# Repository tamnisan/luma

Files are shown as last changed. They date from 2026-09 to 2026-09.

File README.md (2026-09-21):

<div align="center">

# Luma Retrofit: Open-Source Urine Test Strip Reader

**Open-source CAD for a removable urine test strip reader (a urinalysis device) that retrofits into existing public toilets. It needs no drilling, new wiring or plumbing.**

**[Website and live 3D model](https://tamnisan.github.io/luma/)** · **[Build guide](https://tamnisan.github.io/luma/build-guide.html)** · **[Download ZIP](https://github.com/tamnisan/luma/archive/refs/heads/main.zip)**







[Quick start](#quick-start) •
[Open the model](#open-the-model) •
[Design](#design-overview) •
[Build from source](#building-from-source) •
[Status](#project-status) •
[Contributing](#contributing)

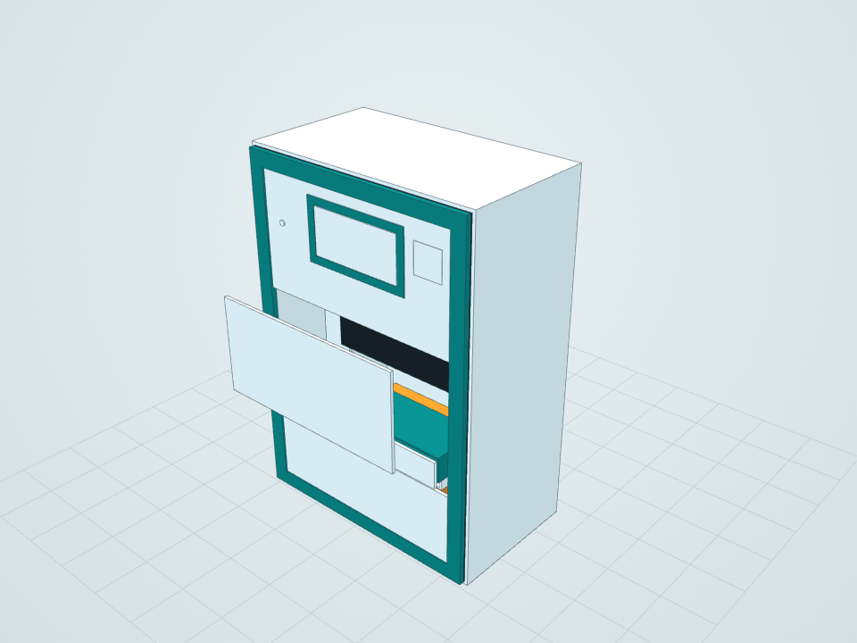
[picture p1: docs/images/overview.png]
Luma reader enclosure, isometric view


</div>

> [!WARNING]
> **This is an engineering prototype (Rev A), not a medical device.** It is not a fabrication release and has not been clinically validated. The sample transport, clamp mechanisms, mount load capacity, sealing and measurement accuracy have not been tested. If you build or deploy anything based on this design, you are responsible for safety, structural and regulatory approval. Read [ENGINEERING.md](ENGINEERING.md) first.

## About

Luma is a compact reflectance reader for urine test strips, designed to be added to public toilets that already exist. One common enclosure takes interchangeable, reversible mounts, so an installer can choose whichever fits the site: a partition edge, a grab-rail post, the top of a cubicle wall, a free-standing pedestal, a smooth tiled surface or structural steel. It runs from a DC supply or a removable battery.

The intended workflow keeps clean and used material apart:

1. The user places a wetted strip in a keyed disposable carrier.
2. The reader checks that the cover is closed and a strip is present.
3. An RGB sensor with two white LEDs scans the pads.
4. The result is shown privately on the display.
5. The used strip goes into a closed waste cartridge.

Unused strips stay in a separate sealed cassette, away from the measurement path.

It is an open-hardware starting point for anyone working on **point-of-care diagnostics**, **smart toilets** or **public health kiosks**. The design reserves space for an **Arduino Uno** controller and a **TCS34725 RGB colour sensor**, and the enclosure is designed for **3D printing** in PC-ABS.

The whole model is **generated by code**: a C# program drives the SolidWorks API, builds every part and assembly from a single dimension table, then checks the result. It is also exported to open formats, so anyone can view, modify, 3D-print or re-use the design **without owning SolidWorks**.

## Highlights

- **109 native SolidWorks parts**, one assembly and a general-arrangement drawing
- **6 reversible mounts × 2 power options = 12 configurations**, plus installed, service and exploded views
- **Works without CAD software:** an offline 3D viewer (double-click `START.html`), STEP files for any CAD program and STL files for 3D printing
- **Parametric and reproducible:** the layout comes from one table in [`src/LumaBuilder.cs`](src/LumaBuilder.cs), and each rebuild is written to a new timestamped folder
- **Checked on every build:** no static interferences in any of the 12 mount/power configurations, all 125 sketches fully constrained, and every part within 0.15 mm of its BOM envelope
- **Documented:** load and stability assumptions, installation site survey, service sequence, mounting-compatibility matrix and cost allowances in [ENGINEERING.md](ENGINEERING.md)

## Gallery

<table>
  <tr>
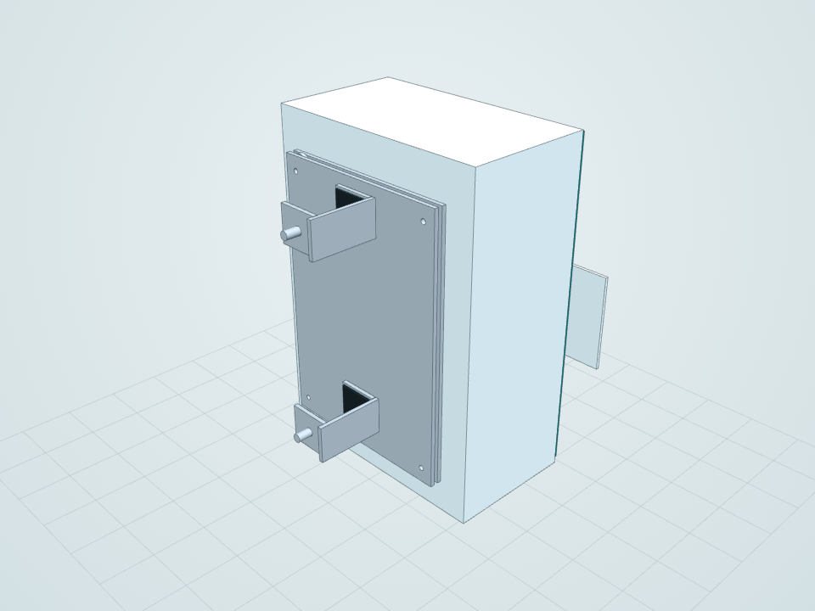
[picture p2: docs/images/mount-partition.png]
Partition clamp mount
    <td align="center"><br><b>Partition clamp</b><br><sub>Padded jaws for 12–50 mm panels</sub></td>
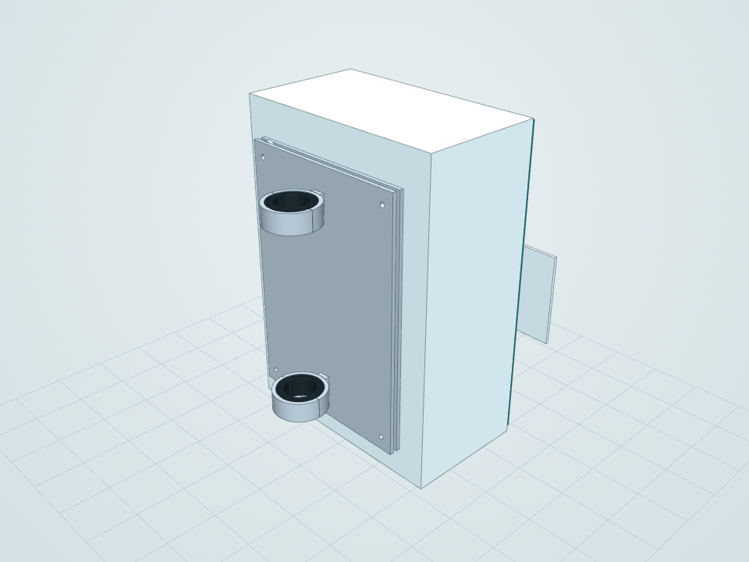
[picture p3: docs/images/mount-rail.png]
Rail clamp mount
    <td align="center"><br><b>Rail clamp</b><br><sub>Split clamp on a 32 mm post</sub></td>
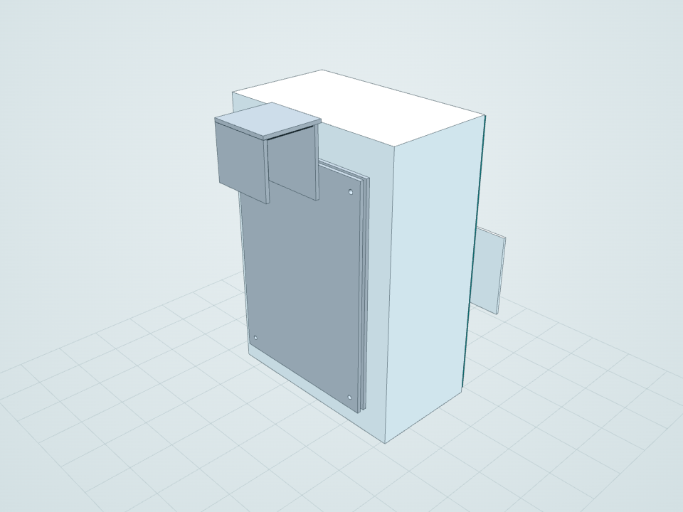
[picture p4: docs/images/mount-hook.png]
Over-partition hook mount
    <td align="center"><br><b>Over-partition hook</b><br><sub>55 mm padded gap</sub></td>
  </tr>
  <tr>
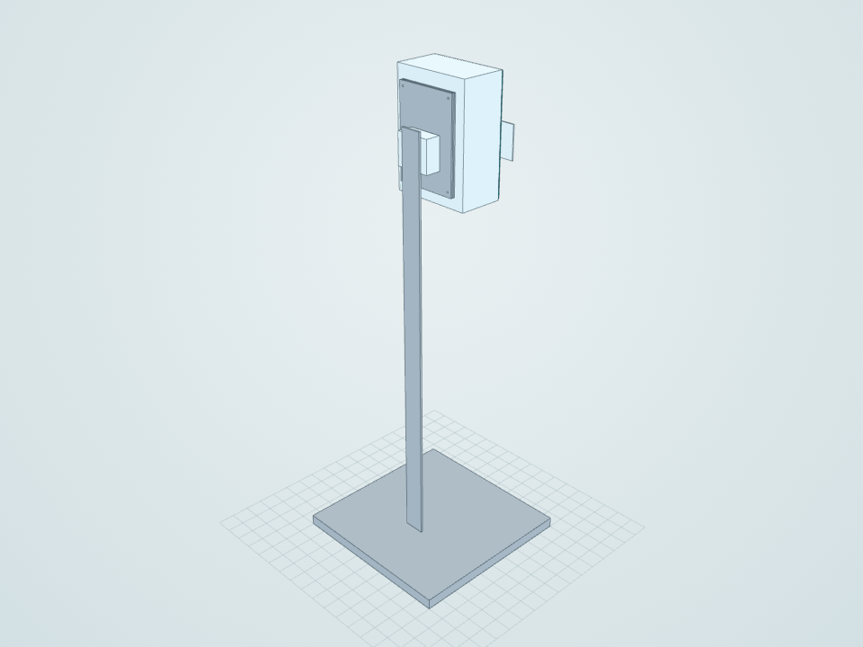
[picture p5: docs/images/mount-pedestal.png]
Floor pedestal mount
    <td align="center"><br><b>Floor pedestal</b><br><sub>Ballasted base, no anchors</sub></td>
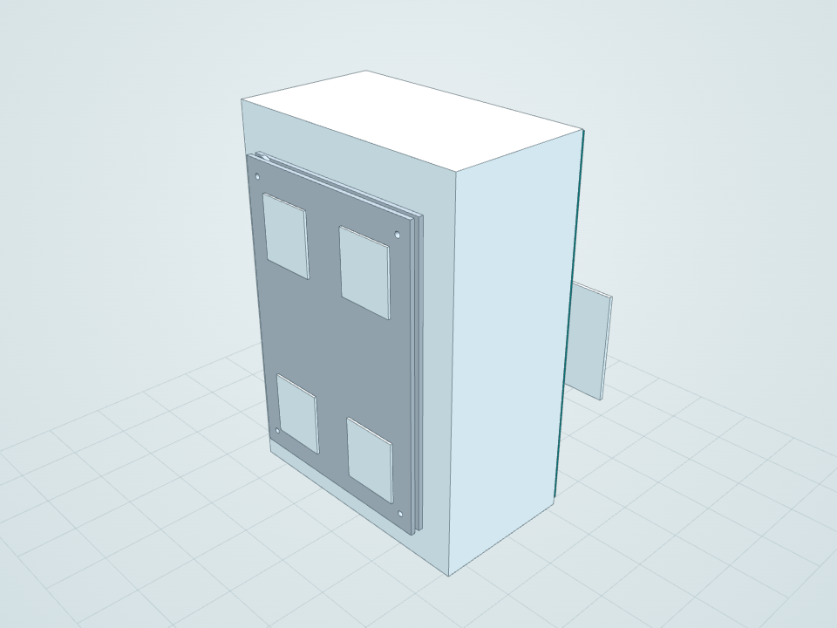
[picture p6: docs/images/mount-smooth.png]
Smooth-surface pad mount
    <td align="center"><br><b>Smooth-surface pads</b><br><sub>Removable pads + tether (reserved)</sub></td>
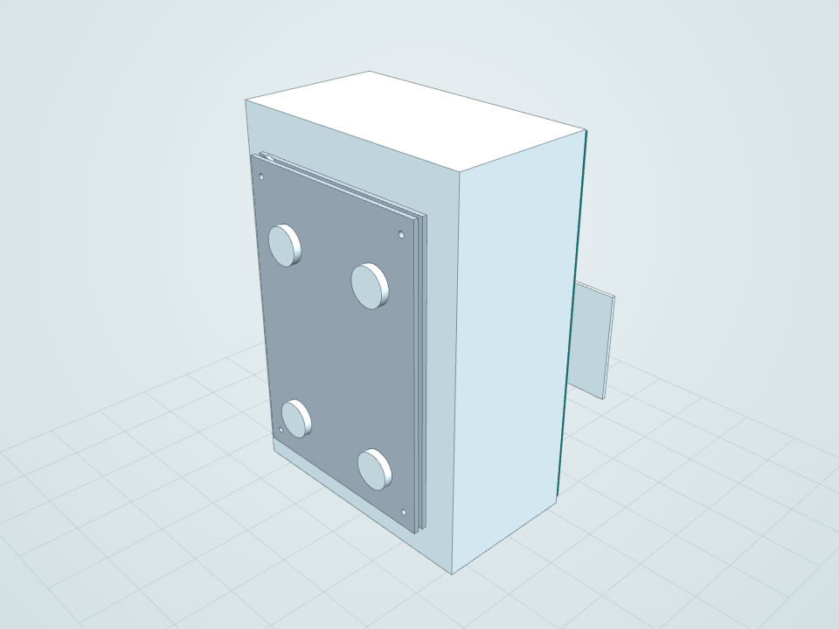
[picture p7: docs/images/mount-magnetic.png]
Magnetic mount
    <td align="center"><br><b>Magnetic mount</b><br><sub>Magnet pots + tether (reserved)</sub></td>
  </tr>
  <tr>
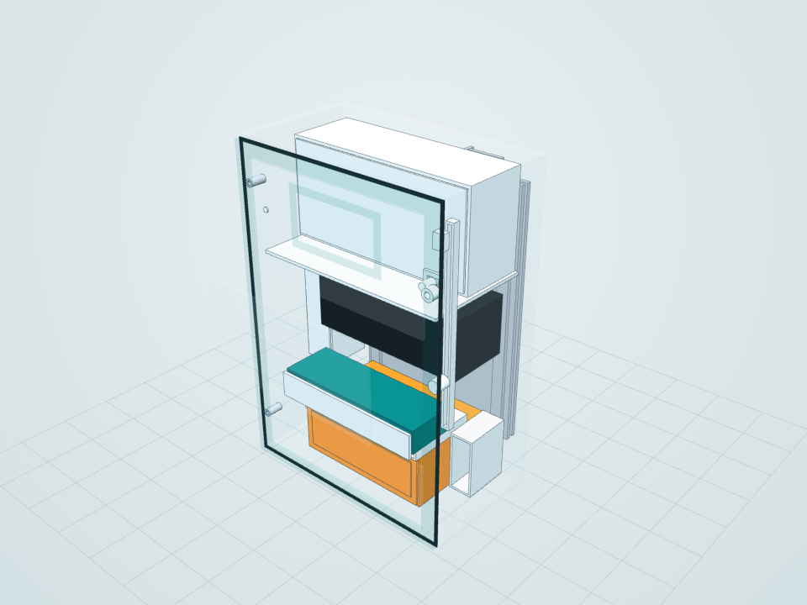
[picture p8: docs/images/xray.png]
X-ray view of the internal layout
    <td align="center"><br><b>Internal layout</b><br><sub>X-ray through the housing</sub></td>
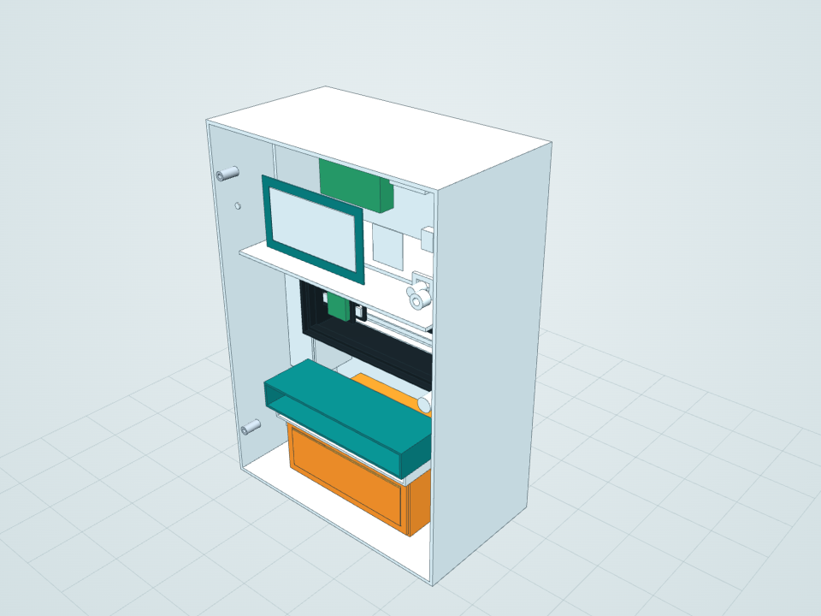
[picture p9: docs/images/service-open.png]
Service view with covers removed
    <td align="center"><br><b>Service access</b><br><sub>Front covers removed</sub></td>
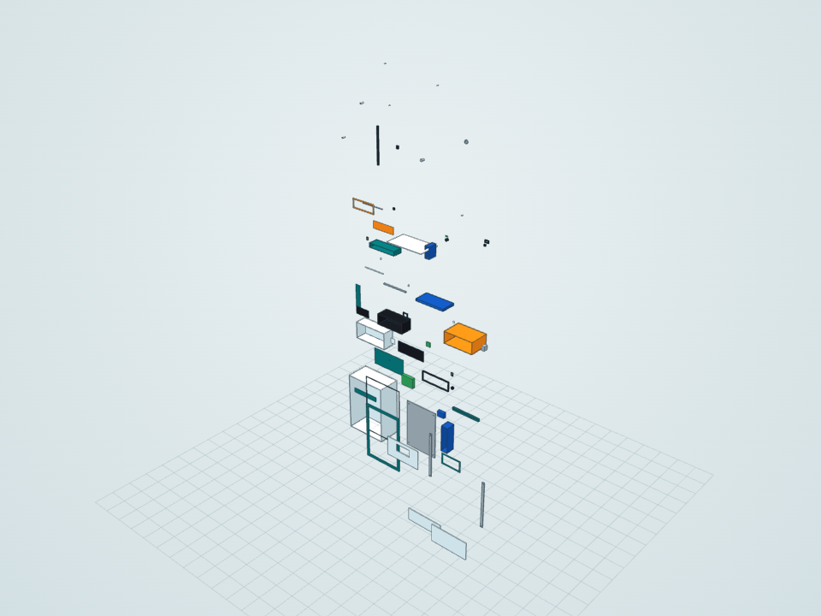
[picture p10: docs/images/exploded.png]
Exploded parts layout
    <td align="center"><br><b>Exploded layout</b><br><sub>Separated-parts review</sub></td>
  </tr>
</table>

<details>
<summary><b>Installed on host infrastructure (illustrative)</b></summary>
<br>
<table>
  <tr>
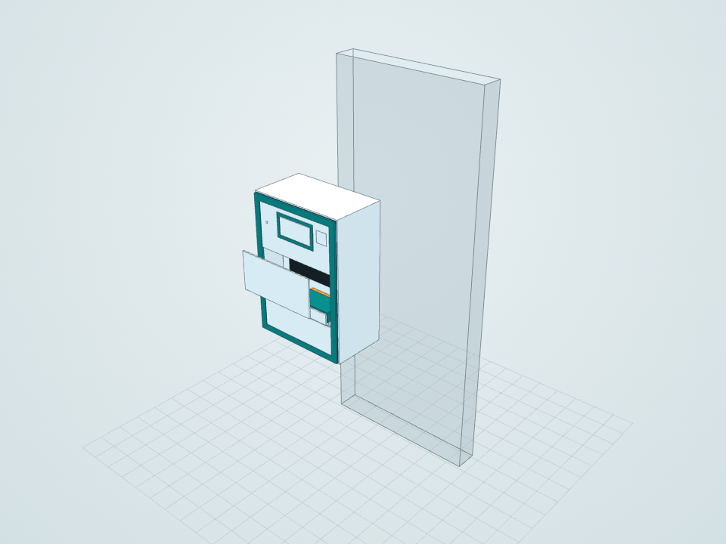
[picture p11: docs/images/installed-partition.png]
Installed on a partition
    <td align="center"><br><sub>Partition</sub></td>
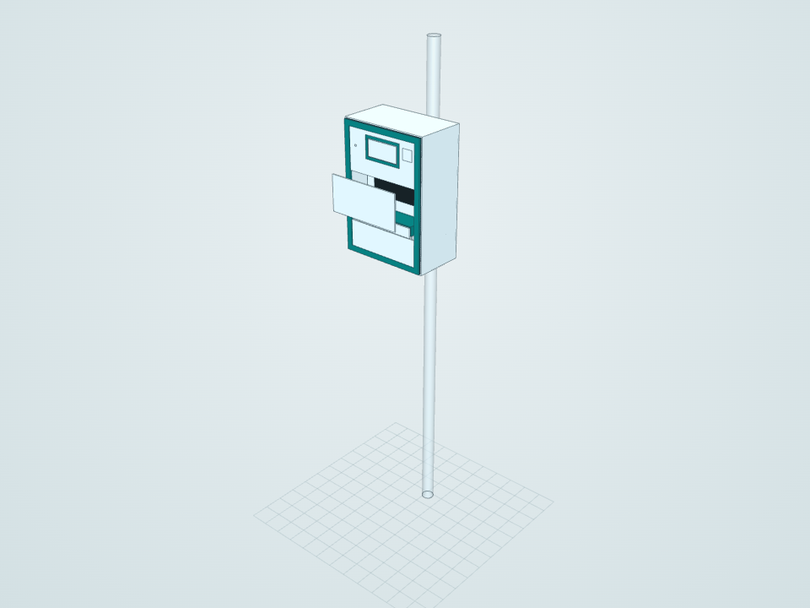
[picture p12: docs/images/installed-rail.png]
Installed on a rail
    <td align="center"><br><sub>Rail / post</sub></td>
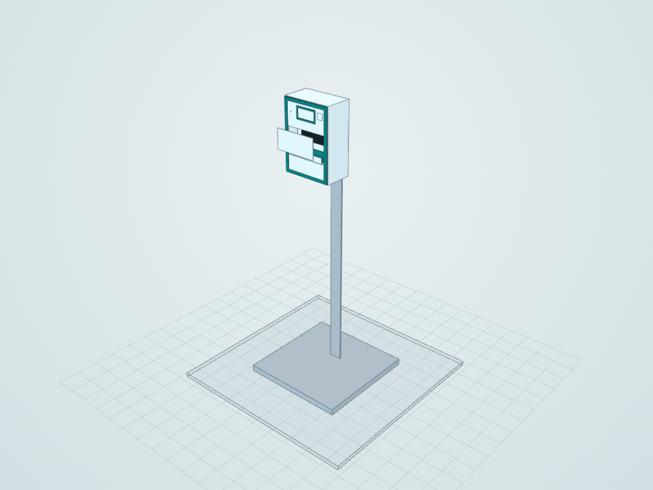
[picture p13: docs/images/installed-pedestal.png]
Installed on a floor pedestal
    <td align="center"><br><sub>Floor pedestal</sub></td>
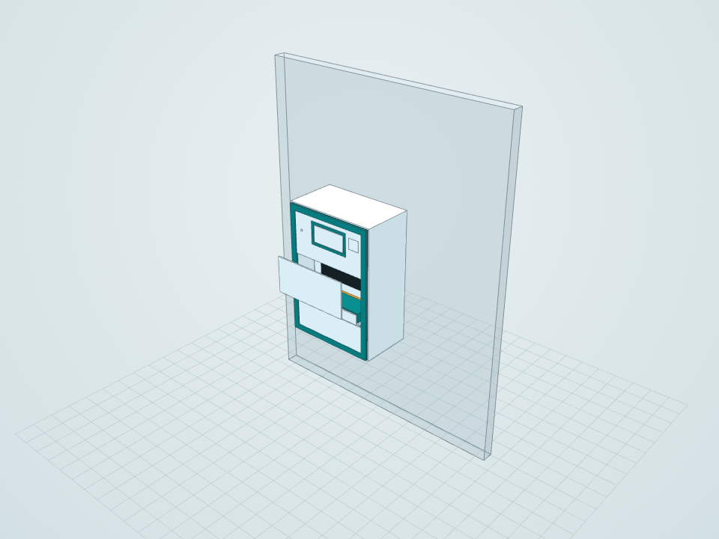
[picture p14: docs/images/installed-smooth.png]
Installed on a smooth wall
    <td align="center"><br><sub>Smooth wall</sub></td>
  </tr>
</table>
The host geometry (panel, post, floor, wall) is reference only and is not part of the product.
</details>

## Quick start

1. **[Download the ZIP](https://github.com/tamnisan/luma/archive/refs/heads/main.zip)** (or **Code → Download ZIP** on GitHub), or clone it:
   ```bash
   git clone https://github.com/tamnisan/luma.git
   ```
2. **Extract** the zip (right-click → *Extract All*). Don't open files from inside the zip, because the viewer and the SolidWorks assembly need their neighbouring files.
3. **Double-click `START.html`.** The interactive 3D model opens in your browser, offline, with nothing to install.

## Open the model

| What you have | What to open |
|---|---|
| **Just a web browser** | `START.html` → [browser 3D viewer](#1-browser-3d-viewer-no-install) |
| **FreeCAD, Fusion 360, Onshape, Inventor, Solid Edge, CATIA, …** | [`exports/step/`](builds/20260913-163314/exports/step/): one STEP assembly per configuration |
| **SolidWorks 2026 or newer** | [`Luma_Retrofit.SLDASM`](builds/20260913-163314/): native parametric model |
| **A slicer / 3D printer** | [`exports/stl/`](builds/20260913-163314/exports/stl/): one STL per part |
| **Nothing downloaded** | Open any `.stl` in [`exports/stl/`](builds/20260913-163314/exports/stl/) on GitHub; it renders a rotatable 3D preview |

### 1. Browser 3D viewer (no install)

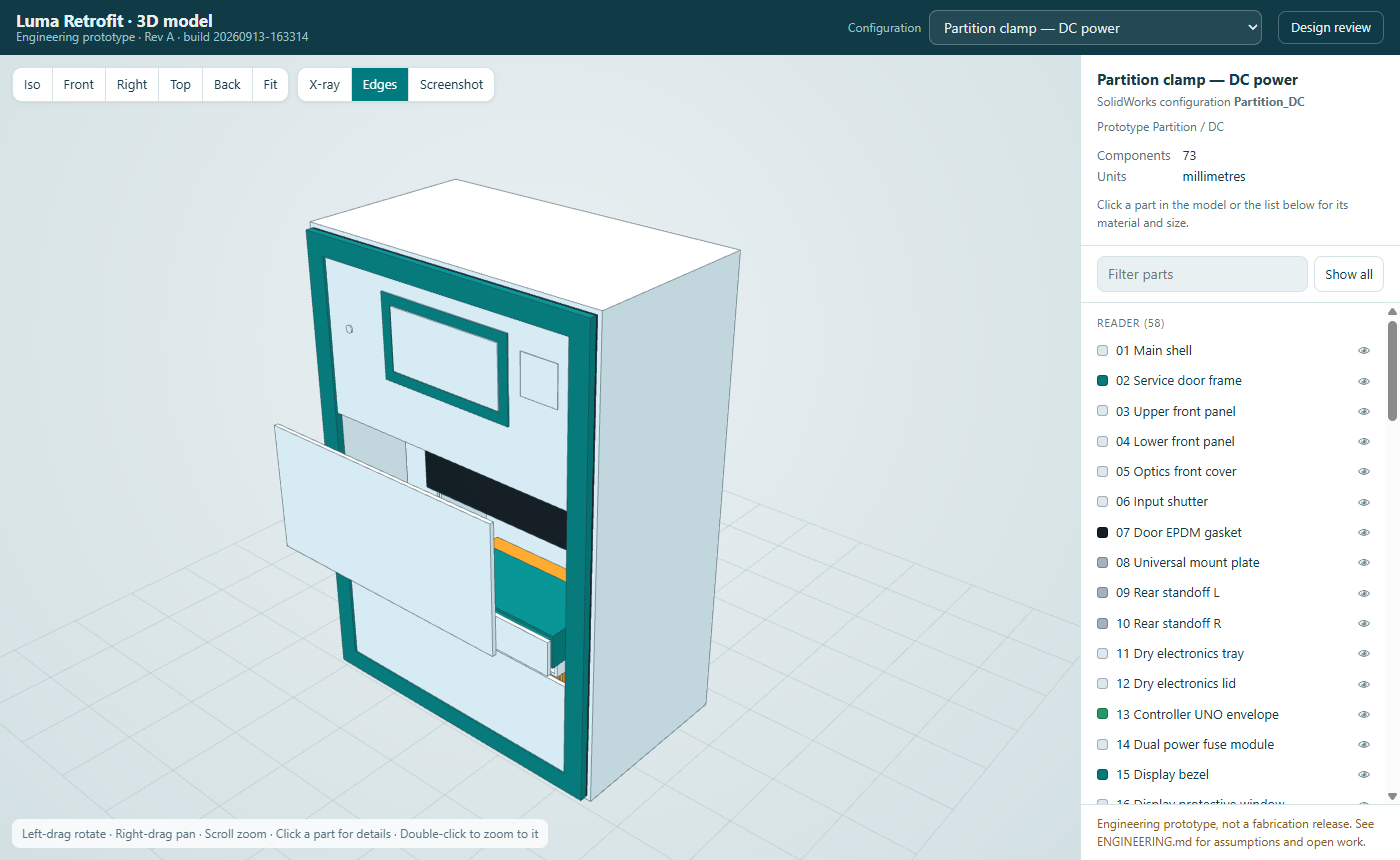
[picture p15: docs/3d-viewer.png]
Luma 3D viewer in the browser


`START.html` opens `builds/20260913-163314/Viewer.html`. It runs offline in current Chrome, Edge, Firefox and Safari.

| Action | How |
|---|---|
| Rotate / pan / zoom | Left-drag / right-drag / scroll |
| Part details (material, process, size, file) | Click a part in the model or in the parts list |
| Zoom to a part | Double-click it |
| See inside the housing | **X-ray** button or `X` |
| Standard views | **Iso / Front / Right / Top / Back** or keys `1`–`5`; `F` to fit |
| Hide or isolate parts | Eye icon in the list, **Isolate** / **Hide** buttons, `H`; `Esc` clears |
| Save an image | **Screenshot** |
| Link to a configuration | Append it after `#`, e.g. `Viewer.html#Rail_Battery` |

A **Design review** link opens [`Review.html`](builds/20260913-163314/Review.html). It holds the dimensioned drawings, native SolidWorks renders, a filterable bill of materials, mass estimates and the engineering record.

> [!TIP]
> **Host the viewer online for free:** in your fork go to **Settings → Pages**, set *Source* to **Deploy from a branch**, choose `main` and `/ (root)`, then save. The model will be viewable at `https://<user>.github.io/<repo>/START.html`.

### 2. STEP (any CAD program)

Each file is a STEP AP214 assembly in millimetres, with colours. Import it with **File → Open / Import**: in FreeCAD use *File → Open*, in Fusion 360 use *Upload*, in Onshape use *Import*.

STEP carries the solid geometry but not SolidWorks' feature history or equations. To change dimensions parametrically, use the generator ([Building from source](#building-from-source)).

### 3. SolidWorks (native, parametric)

Open `builds/20260913-163314/Luma_Retrofit.SLDASM` and keep its `parts/` folder beside it. Choose a configuration in the **ConfigurationManager**. Also included are `Luma_Exploded.SLDASM` (separated-parts assembly) and `Luma_GA.SLDDRW` (general-arrangement drawing).

> [!NOTE]
> SolidWorks files open only in the version that saved them or newer, so these need **SolidWorks 2026+**. The free [eDrawings Viewer](https://www.edrawingsviewer.com/) has the same version requirement. On older versions, use the STEP files.

### 4. STL (3D printing)

These are binary STL files in millimetres, one per part, each in its own coordinate system. Check the `Process` column in [`BOM.csv`](builds/20260913-163314/BOM.csv) first. Parts named `*_envelope` only reserve space for purchased components (Arduino, sensor, battery, motor, …), and items marked COTS should be bought, not printed.

## Build it yourself

The **[build guide](build-guide.html)** ([online](https://tamnisan.github.io/luma/build-guide.html)) covers building a prototype:

- the full parts list with specifications, each checked against the space the CAD reserves: Arduino Uno, TCS34725 colour sensor, white LEDs, micro stepper, 2S battery, switches, and the printed, stainless-steel and EPDM parts
- labelled layout diagrams showing where every component goes (the Arduino sits upright in the upper-left corner of the dry electronics compartment)
- eight assembly steps, each with a picture and a link that highlights those parts in the 3D viewer
- a suggested Arduino wiring table, power path, first power-up tests and the service routine

## Configurations

| Mount | DC power | Battery power | Installed on host (illustrative) |
|---|---|---|---|
| Partition clamp | `Partition_DC` | `Partition_Battery` | `Installed_Partition` |
| Rail clamp | `Rail_DC` | `Rail_Battery` | `Installed_Rail` |
| Over-partition hook | `Hook_DC` | `Hook_Battery` | none |
| Floor pedestal | `Pedestal_DC` | `Pedestal_Battery` | `Installed_Pedestal` |
| Smooth-surface pads | `Smooth_DC` | `Smooth_Battery` | `Installed_Smooth` |
| Magnetic mount | `Magnetic_DC` | `Magnetic_Battery` | none |

There is also `Service_Open` (front covers removed) and the separate exploded assembly. The STEP file for each configuration is `exports/step/Luma_<Configuration>.step`.

## Design overview

| | |
|---|---|
| **Enclosure envelope** | 230 W × 330 H × 134 D mm; 150 mm projection including the rear adapter |
| **Estimated dry mass** | ≈ 5.4 kg (partition / DC). This is an analytic estimate from geometry and assumed densities, not a weighed or certified value |
| **Electronics allowance** | Arduino Uno, TCS34725 RGB sensor, two white LEDs, display, status LED, buzzer, dual power fuse module |
| **Optics** | Enclosed black optical chamber, moving sensor/LED scan carriage on a rail with lead screw and motor, calibration tile |
| **Consumables** | Sealed clean-strip cassette, sample drawer, used-strip waste cartridge with closure slide, drip tray, cleaning-fluid cartridge |
| **Power** | DC connector with cable gland and strain relief, **or** a removable battery tray (75 × 23 × 39 mm protected-pack allowance) |
| **Safety interlocks (reserved space)** | Door interlock, cartridge-present switch, drip-overflow sensor, strip-jam/home sensor, service lock, tether eye |
| **Common mount interface** | 180 × 260 × 4 mm stainless adapter plate, 4 × Ø5 mm holes; no new holes in the building |
| **Materials** | PC-ABS (printed enclosure), black PC-ABS (optics), polypropylene (wetted trays and cartridges), 304 stainless steel (mounts, hinges, fasteners), EPDM (gaskets and pads), polycarbonate (display window) |
| **Prototype cost allowance** | INR 8,867–18,667 before stand, connectivity, labour and validation (planning figures, not quotes) |

| Zone | Layout |
|---|---|
| Dry electronics | Upper tray with sealed lid, full wet/dry barrier below |
| Unused strips | Separate left cassette with removable lid |
| Optics | Right central chamber, black insert, moving RGB/LED carriage, fixed strip datum |
| Sample input | Removable front tray behind a shutter |
| Waste | Lower removable cartridge with closure slide |
| Cleaning | Small fluid-cartridge allowance plus removable wetted inserts |

The full site-suitability rules for each mount, load cases, stability checks, assembly and service sequence, and installer survey are in [ENGINEERING.md](ENGINEERING.md).

## Repository structure

```
luma/
├── START.html                    Opens the 3D viewer
├── index.html                    Project website (GitHub Pages homepage)
├── build-guide.html              Parts list, layout diagrams, assembly steps and wiring (generated by src/Guide.js)
├── assets/site.css               Shared website styles
├── README.md                     This file
├── ENGINEERING.md                Design intent, assumptions, mounting matrix, loads, service, costs, open work
├── LICENSE                       MIT
├── CITATION.cff                  Citation metadata ("Cite this repository")
├── sitemap.xml                   Sitemap for search engines
├── LATEST.txt                    Name of the current build folder
├── docs/                         README and build-guide images, social preview card
├── builds/
│   └── 20260913-163314/          Current build
│       ├── Viewer.html, viewer/  Offline 3D viewer and its model data
│       ├── Review.html           Design review (drawings, renders, BOM, engineering record)
│       ├── Luma_Retrofit.SLDASM  Main assembly (+ Luma_Exploded.SLDASM, Luma_GA.SLDDRW)
│       ├── parts/                109 native SolidWorks parts
│       ├── exports/step/         STEP assembly per configuration
│       ├── exports/stl/          STL mesh per part
│       ├── exports/scene.json    Component placement per configuration
│       ├── BOM.csv               Part envelopes, positions, materials, processes
│       ├── views/                Native SolidWorks renders
│       └── VALIDATION.md, *.txt  Rebuild, sketch, geometry and interference check records
└── src/                          Generator, checks, exporter, viewer and report source
```

## Building from source

The CAD is produced by a pipeline you can re-run, change and extend.

```mermaid
flowchart LR
    A["LumaBuilder.cs<br/>dimension table"] --> B["Parts, assembly,<br/>12 configurations"]
    B --> C["Verify, repair, detail<br/>and interference checks"]
    C --> D["Export.cs"]
    D --> E["STEP per configuration"]
    D --> F["STL per part"]
    D --> G["scene.json"] --> H["Viewer.js: 3D viewer"]
    C --> I["Audit.js + Report.js:<br/>VALIDATION.md, Review.html"]
```

### Requirements

- Windows with **SolidWorks 2026 or newer** and a licence
- .NET Framework 4.x (included with Windows)
- [Node.js](https://nodejs.org) 18+ for the viewer and reports
- Default templates set in SolidWorks (**Tools → Options → Default Templates**)

The SolidWorks install is found through the registry. Set `SOLIDWORKS_DIR` to use a different one.

### Commands

```powershell
# Full rebuild into a new builds\<timestamp> folder (updates LATEST.txt)
powershell -ExecutionPolicy Bypass -File src\Build.ps1

# After editing the current model in SolidWorks: refresh STEP, STL, the 3D viewer and the review
powershell -ExecutionPolicy Bypass -File src\Build.ps1 -ExportOnly

# Zip the current build (e.g. to attach to a GitHub Release)
powershell -ExecutionPolicy Bypass -File src\Package.ps1
```

Run only one builder at a time against a SolidWorks instance. The exporter opens the model read-only and restores your export settings afterwards.

### Changing the design

Every part's size and position is in `Layout()` in [`src/LumaBuilder.cs`](src/LumaBuilder.cs), in millimetres. Edit it and run a full rebuild. Parts are built from sketches and extrusions whose dimensions are linked to global variables. There is no master skeleton or mechanical mates yet, so a change to one part does not resize its neighbours automatically.

| Source | Purpose |
|---|---|
| `src/LumaBuilder.cs` | Generates every part, the assembly and its configurations |
| `src/Verify.cs` | Reopens and rebuilds parts, constrains sketches, measures bodies, checks interference |
| `src/RepairConfigurations.cs`, `Scenes.cs`, `Finalize.cs`, `FinalAudit.cs` | Configuration checks, host reference scenes, exploded assembly, final views |
| `src/HardwareDetails.cs` | Screw clearances, rail-saddle relief, hook-plate separation |
| `src/Export.cs` | STEP per configuration, STL per part, placement data for the viewer |
| `src/Viewer.js`, `src/Viewer.html` | Builds the offline viewer and checks each placement against SolidWorks' own component boxes |
| `src/Audit.js`, `src/Report.js` | Validation record, design review and dimensioned SVG drawings |
| `src/Guide.js` | Website build guide: parts tables, layout diagrams and assembly steps from `BOM.csv` |

## Project status

**Rev A: packaging and layout prototype.** What exists and what still has to be done:

- [x] Native, reproducible CAD for the enclosure, internals and six mounts
- [x] All sketches fully constrained; zero static interferences in all 12 mount/power configurations
- [x] Open-format exports and a browser viewer
- [x] Engineering record: assumptions, load cases, site survey, service sequence, cost allowances
- [ ] Mechanical mates, bearings, travel stops and a motion study for the scan mechanism
- [ ] Detailed strip feed/eject kinematics and jam/carry-over testing
- [ ] Optical bench study: sensor distance, LED angle, pad-specific calibration
- [ ] Seals, drainage and an IP54/IP55 enclosure test
- [ ] Mount load, creep and surface-damage tests; clamp hardware detailing
- [ ] Manufacturing detail: fillets, draft, ribs, bosses, threaded inserts, tolerances
- [ ] Electrical interlocks, firmware and user interface
- [ ] Analytical and clinical validation for the chosen test strips

See *Verification and remaining development* in [ENGINEERING.md](ENGINEERING.md#verification-and-remaining-development) for the evidence needed for each item.

## Contributing

Contributions are welcome, whether design improvements, test results, fixes or documentation.

1. **Open an issue** to report a problem or propose a change. For design issues, name the configuration and part (e.g. `Rail_DC`, `27_Scan_rail`).
2. **Fork** the repository and create a branch.
3. **Make the change in the generator** (`src/`) rather than editing parts by hand, so it stays reproducible. Then run `src\Build.ps1`, or `-ExportOnly` if you edited the model directly.
4. **Commit the new build folder** with its `exports/`, `viewer/` and check records, and update `LATEST.txt`. Don't commit `.exe` or SolidWorks `.dll` files; `.gitignore` excludes them.
5. **Open a pull request** that describes what changed and how you checked it: the rebuild log, `VALIDATION.md` and `final-interferences.txt`.

No SolidWorks licence? You can still help: review the design in the viewer or STEP files, check the engineering assumptions, share physical test data, or improve the documentation.

## License

This project is released under the [MIT License](LICENSE) © 2026 tamnisan. You may use, copy, modify, manufacture, distribute and sell it, commercially or not, as long as you keep the copyright notice. The design comes **as is, without any warranty**. Anyone who builds or deploys it is responsible for its safety and regulatory compliance.

**Third-party components:** the viewer bundles [three.js](https://threejs.org) r147 under the MIT License ([`src/vendor/three-LICENSE.txt`](src/vendor/three-LICENSE.txt)). SolidWorks and eDrawings are trademarks of Dassault Systèmes; this project is not affiliated with or endorsed by Dassault Systèmes.

## Citation

If you use this design in research or a derived project, please credit it:

```bibtex
@misc{luma_retrofit_2026,
  title        = {Luma Retrofit: an open CAD design for a removable urine-strip reader for public toilets},
  author       = {tamnisan},
  year         = {2026},
  howpublished = {\url{https://github.com/tamnisan/luma}},
  note         = {Engineering prototype, Rev A}
}
```

## Acknowledgements

- Concept based on the *Smart Health Kiosks: Democratizing Diagnostics via Public Infrastructure* presentation.
- 3D viewer built with [three.js](https://threejs.org).
- Geometry generated through the [SolidWorks API](https://help.solidworks.com/2026/english/api/sldworksapi/welcome.htm).

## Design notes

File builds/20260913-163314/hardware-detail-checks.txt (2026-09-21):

09_Rear_standoff_L cut=Fastener_clearance rebuild=True saveErrors=0
10_Rear_standoff_R cut=Fastener_clearance rebuild=True saveErrors=0
Partition_moving_jaw_0 cut=Fastener_clearance rebuild=True saveErrors=0
Partition_moving_jaw_1 cut=Fastener_clearance rebuild=True saveErrors=0
Rail_bridge_0 cut=Saddle_contact_relief rebuild=True saveErrors=0
Rail_bridge_1 cut=Saddle_contact_relief rebuild=True saveErrors=0

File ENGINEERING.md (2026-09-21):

# Luma / Rev A engineering prototype

## Design intent and status

Luma is a removable urine-strip reflectance-reader module for existing public toilets. This package is a native SolidWorks engineering layout and reproducible C# generator. It is a prototype starting point, not a clinically validated instrument or fabrication release. Read `checks.txt` and `sketch_checks.txt` in the latest build for actual CAD results. No design certification is implied by the renderings.

The envelope is 230 mm wide × 330 mm high × 134 mm deep, with the rear adapter datum at z = -16 mm, giving a nominal 150 mm projection. Mounts can add rearward depth: 150 mm is the main unit/interface envelope, not a claim that every clamp installation occupies only 150 mm. Coordinates: x left/right, y upward from case bottom, z forward from case rear. Floor stand layouts place the kiosk bottom about 1,000 mm above the base top; final installation height needs a site-specific reach assessment.

Requirements originating in the supplied presentation include the 300–350 × 200–250 × 120–150 mm envelope, TCS34725 sensor, two white LEDs, Arduino Uno, 14-pad strip concept, private results and front servicing. The source presentation's INR 2,667 estimate covers a sensor, Uno, strips, LEDs and jumpers only. It does not establish the cost of an enclosure, mounts, automation, battery, display, or waste system.

## Mechanical architecture

| Zone | Layout / rationale | Open design work |
|---|---|---|
| Dry electronics | Upper tray, sealed lid, full wet/dry shelf below | Select feedthroughs and gasket compression; no leak test performed |
| Unused strips | Separate left cassette with removable lid | Strip supplier and moisture barrier/desiccant system required |
| Optics | Right central chamber, black insert, moving RGB/LED carriage and stationary strip datum | Optical brackets and scan drive require development and calibration |
| Sample input | Front removable tray behind shutter | Manual strip insertion is Rev A; powered transfer to optical datum is not validated |
| Waste | Lower removable tray/cartridge; closure slide for removal | Transfer/ejection chute and self-closing seal require detailed development |
| Cleaning | Independent small fluid-cartridge allowance plus removable wetted inserts | Washing sequence, drain isolation and carryover tests required |
| Power | Battery tray configuration or DC connector configuration | Actual pack, BMS, fuse and rated connector selection required |
| Interface | Display bezel/window, QR area, indicator and lock | Display mount angle, wiring and software are prototype tasks |

The clean cassette is separate from the contaminated measurement path. Baseline operating concept: operator/user inserts an already wetted strip in a keyed disposable carrier; reader checks cover closure and strip presence; optics scan; user receives a private result; used strip goes into a closed waste cartridge. The CAD includes packaging for future feed/eject and cleaning functions. It does not demonstrate a fully automatic urine sampling mechanism. Do not present a clean cassette plus motor envelope as proof of automatic dispensing or fluid handling.

Screen/SMS/payment/clinical algorithms are outside this mechanical CAD implementation. In particular, an offline device cannot verify a new UPI payment or deliver SMS without a suitable connection; local measurement and local display are the offline workflow.

## Configurable dimensions and measured inputs

The generator's `Layout()` lists every part dimension and position in mm. Every extruded feature has a global depth variable. Auto-defined sketch dimensions are linked to individual global variables named `Profile_Sketch_N` or `Back_Sketch_N`. `EnvelopeWidth` and `EnvelopeHeight` are reference metadata, not master assembly controls. To change the whole layout consistently, edit `Layout()` and rebuild into a new timestamped directory. Local edits to one part do not automatically resize adjacent parts.

| Parameter | Prototype value / investigation range | Evidence needed |
|---|---|---|
| Case W/H | 230 / 330 mm | Packaging build and installed clearances |
| Shell / adapter thickness | 3 / 4 mm | Print trials and structural checks; optimise steel mass |
| Strip envelope | 125 × 5 × 0.5 mm | Measure purchased strip, including handle |
| Sensor board envelope | 21 × 21 × 5 mm | Supplier drawing; not all TCS34725 boards match |
| UNO envelope | 69 × 54 × 16 mm | Board plus cable/connector height |
| Sensor-to-pad spacing | Initial envelope around 10–20 mm; explore 5–25 mm on optical jig | Read repeatability, saturation, pad crosstalk |
| LED angle | Explore 30–60° to pad plane | Specular rejection and uniformity tests; brackets presently schematic |
| Pad centres / scan stroke | Supplier-specific; proposed ~100 mm scan range | Actual pad positions and lead-screw travel |
| Pad reaction times | Supplier-defined per pad | Do not use one universal read time |
| Partition thickness | Intended 12–50 mm; represented at 50 mm | Jaw adjustment, screw travel and pad load tests |
| Rail/post diameter | 32 mm insert shown; intended 25/32/38 mm variants | Exact rail geometry, stiffness and permitted load |
| Hook opening | Nominal 55 mm padded gap | Partition top condition, thickness and overhead clearance |
| Battery | 75 × 23 × 39 mm allowance | Energy budget and purchased protected pack |
| Waste capacity | Compute from CAD cavity; do not infer test count from gross volume | Strip stacking, liquid retention and service interval |
| Service space | Reserve 250 mm in front as an initial survey allowance | Full door swing and withdrawal trials |

No assumptions about test-strip chemistry, sensitivity or clinical accuracy are validated here. Fourteen listed analytes do not establish that the selected strip and reader can measure all fourteen reliably.

## Mounting compatibility matrix

All adapters use a common 180 × 260 mm plate with Ø5 mm mounting clearances at x = ±78 mm, y = 49 and 281 mm. Rear stand-offs include Ø4.5 mm screw clearances; the clamp moving jaws include simplified Ø8.1 mm screw passages. Rail bridges have a cylindrical contact relief matching the clamp's 27 mm outside radius. Thread retention, nuts, shoulders, clamp ears and captive-fastener details still require mechanical development before manufacture. Existing infrastructure supplies no new drilled holes.

| Configuration | Suitable site | Exclusions / prerequisites | Reversible installation |
|---|---|---|---|
| Partition | Accessible edge of a structurally suitable 12–50 mm partition | No thin loose sheet, glass edge, fragile finish, moving door or uncertain panel anchorage | Padded opposed jaws and installer-adjusted screws; concept needs load test |
| Rail/post | Approved structural post with unobstructed grip/access zone | Do not load water/flush pipes or impair a required grab rail; obtain asset-owner load information | Split clamp halves, replaceable elastomer inserts and anti-rotation bridge |
| Over-partition hook | Sound exposed partition top | No door closer, door movement or head-clearance conflict; no glass without approved hardware | Padded hook, anti-lift restraint and positive anti-rotation attachment |
| Weighted pedestal | Level floor with enough space and cleaning access | Reject wet slippery/uneven sites unless measured stability and slip resistance pass; no obstructed route | Place and level without anchors; heavy base needs handling provision |
| Smooth surface | Qualified glass/glazed tile with tested mounting product | Reject porous/rough/contaminated surfaces, damaged tile, unknown substrate or no independent tether point | Selected rated removable system; presently not approved for deployment |
| Magnetic | Verified ferromagnetic structural steel | No aluminium, austenitic stainless, thin unsupported sheet, loose coating or no independent tether point | Rated magnetic pots, shear-resisting arrangement and independent tether |

Adhesive and magnetic adapters are reserved configurations, not verified attachment solutions. A safety tether requires an existing suitable independent anchor; if none exists, reject these methods and consider a different mount. No mount is universally compatible. The common enclosure stays consistent while the installer chooses a compatible attachment and checks user clearances.

## Load and stability assumptions

Use the computed component-volume estimate in the generated report as a preliminary dry mass only. Purchased-part densities are placeholders. Add consumables, retained liquid, wiring, all fasteners and manufacturing changes. For initial attachment study use a conservative 10 kg supported device allowance and evaluate 100 N outward and lateral user loads separately. These are chosen design cases, not requirements from a cited standard.

- Gravity for 10 kg: 98.1 N. With 3× static allowance, investigate 294.3 N vertical attachment capacity.
- At a 90 mm centre-of-mass offset, dead-load moment is 8.83 N·m; with that allowance it is 26.5 N·m.
- A 100 N outward load can add a moment depending on its actual application point. Never add moments without checking direction and lever arm.
- Clamp shear estimate: required total normal force N ≥ design shear / measured coefficient of friction. At provisional μ = 0.3 and design shear 294.3 N, N ≥ 981 N across contact faces. Wet friction may be much lower; this is not a clamp rating or tightening-torque prescription.
- The 500 × 500 × 30 mm steel ballast envelope is 60 kg at 8,000 kg/m³. Base-only restoring moment about an edge is approximately 147 N·m when centred. A 100 N horizontal force at 1.30 m gives 130 N·m, margin only 1.13 before sliding or offsets. A 150 N force gives 195 N·m and fails this base-only assessment. Do not call this pedestal vandal-resistant or tip-certified. Its footprint/mass conflict needs site-specific resolution.
- Sliding check uses measured wet-floor friction: R = μ × total weight. Tipping resistance does not establish resistance to sliding.

The CAD density defaults are not engineering material assignments. The generated report estimates mass from explicit geometric volumes and listed densities; SolidWorks mass properties must not be used as certified values until production materials and purchased-component masses are assigned. The final exploded layout is in a separate `Luma_Exploded.SLDASM` document because fixed-component position changes propagated across configurations during testing. `final-interferences.txt` supersedes earlier interference logs after the installed positions are restored.

## Assembly and service sequence

1. Assemble shell, dry compartment, barrier and rear plate. Fit actual seals and perform leak inspection before electronics.
2. Install optical chamber on repeatable datums; install sensor/LED modules and calibration reference. Confirm dark reading with covers closed.
3. Install strip guide, sample carrier and drive hardware. Prove motion and jam recovery without samples before fluid testing.
4. Fit electrical modules, protected battery or DC input, fuse, glands and strain relief. Keep cable routes above liquid retention regions.
5. Fit removable clean cassette, sample drawer, drip tray, cleaning insert and waste cartridge. Verify that each removes from the front without exposure of clean stock.
6. Fit front panels, display window, lock, hinges and interlock. The current CAD uses separate panel bodies; final door fasteners and full hinge swing require detailing.
7. Choose a compatible mount using the survey below. Perform an instrumented proof test off-site before public deployment.
8. Maintenance: disable motion; close waste cartridge slide; withdraw and replace waste cartridge; remove/wash or replace wetted insert; inspect seals; refill clean stock through the clean access path; replace protected battery if used; close and lock covers; run reference and sensor checks.

The used-strip cartridge must not be emptied through the clean compartment. The cartridge slide must close before removal. Opening the service door disables motion; a missing/full cartridge inhibits testing; jam/overflow states stop further sample intake. Sensor boxes in the model reserve these functions but do not implement electrical interlocks.

## Site survey / installer record

- Record fixture type, photographs, mounting surface dimensions, owner approval, material and structural condition.
- Measure free width/depth, opening doors, cleaner access and remaining circulation space.
- Identify accessible partition edge or qualified support, exact thickness/diameter and a compatible mount.
- Determine permitted surface pressure, clamp load and removable-product compatibility with the finish.
- Check display/sample reach with intended users; inspect for privacy conflicts and sharp/pinch points.
- Verify clear access to flush controls, grab rails, toilet/urinal, door latches and emergency routes.
- Identify existing safe power source or use a removable battery. No new building wiring or plumbing.
- Check the actual installed projection including mount hardware and cable bend radius.
- Confirm front service space and a hygienic route for replacement cartridges.
- For optional mounts, record tether anchor, substrate verification and applicable supplier rating.
- For pedestal, measure levelness and wet friction; prove stability at actual mass, height and applied loads.
- Reject the site if none of the reversible options passes these checks.

## Verification and remaining development

| Item | Current evidence | Required before fabrication/deployment |
|---|---|---|
| Native geometry / rebuild | CAD generator checks extrusions and saves; inspect generated logs | Reopen all final references and resolve rebuild errors |
| Sketch constraint state | 125 inspected sketches fully constrained after final detailing; state 3 | Recheck after dimensional or mechanism changes |
| Interference | SolidWorks static interference log for default configuration | Classify intentional contact, resolve unintended overlap; inspect all moving states |
| Envelope | Part and assembly bounding checks in report | Actual mount and site envelope verification |
| Optical geometry | Layout only | Bench study, repeatable datums, black finish, pad-specific calibration |
| Feed/eject | Packaging allowance | Detailed kinematics and physical strip-jam/carryover tests |
| Hygiene | Separated compartments and removable trays | Leak, cleaning efficacy, liquid carryover, disinfectant compatibility |
| IP54/IP55 | Design target only | Selected seals, drainage/vents and tested complete enclosure |
| User/service clearance | Concept envelope only | Door sweep, reach, pinch-point and maintenance demonstration |
| Reversible mounts | CAD concepts | Load paths, clamp hardware, surface damage and creep/pull tests |
| Manufacturing | Printed prototype and steel bracket concepts | Fillets, draft, rib/boss design, bend radii, tolerances, threaded inserts |
| CAD assembly mechanism | Fixed components for packaging | Mates, bearings, linkages, travel stops and motion study |
| Clinical performance | None | Appropriate analytical/clinical validation for chosen consumables |

Optional external auto-flush actuator is deliberately not installed in this baseline: no specific existing flush-button or lever geometry was supplied, and core measurement is independent of plumbing. A future removable actuator must preserve manual operation and spring-return safely on power loss.

## Prototype cost allowances (INR, not supplier quotes)

| Category | Planning allowance |
|---|---:|
| Sensor, Uno, LEDs and wiring | 1,167 from presentation, excludes its strip pack |
| 100-strip pack | 1,500 from presentation; confirm supplier and compatibility |
| Printed enclosure / removable trays | 2,000–4,500 |
| One mechanical mount / locks / seals / fasteners | 1,500–3,500 |
| Display / interface | 500–1,500 |
| Motion / bearings / driver / interlocks | 1,000–3,000 |
| Power / protection | 700–2,000 |
| Optical finish / calibration / cleaning provisions | 500–1,500 |
| Total, before stand / connectivity / labour / validation | 8,867–18,667 |

Do not claim the complete kiosk meets an INR 3,000 target. The heavy pedestal, tooling and clinical validation are separate costs. Use these allowances to decide what to prototype first, then replace them with dated supplier quotes.

## Source and reproducibility

Source idea: `Smart-Health-Kiosks-Democratizing-Diagnostics-via-Public-Infrastructure.pdf.pdf`, supplied by the user, especially pages 4–7, 10–11. User's pasted request controls scope; the PDF is supporting reference material. Geometric/API implementation follows local SOLIDWORKS 2026 interop signatures and official documentation:

- https://help.solidworks.com/2023/English/api/sldworksapi/SOLIDWORKS.Interop.sldworks~SOLIDWORKS.Interop.sldworks.ISketchManager~CreateCornerRectangle.html
- https://help.solidworks.com/2020/English/api/sldworksapi/Insert_Feature_Extrusion_Example_VB.htm

Run `src/Build.ps1` from Windows PowerShell on the same Windows installation with a licensed, available SolidWorks 2026. The script compiles a 64-bit .NET Framework C# executable against installed interop libraries. No API key or cloud CAD service is needed. It creates a new timestamped build and never overwrites prior builds or user CAD models. The SolidWorks install folder is read from the registry (override with the `SOLIDWORKS_DIR` environment variable) and new documents use the default templates set in SolidWorks under Tools > Options > Default Templates, so no paths need editing on another PC.

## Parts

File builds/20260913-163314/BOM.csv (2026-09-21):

Part | Configuration_group | Shape | Width_mm | Height_mm | Depth_mm | Wall_mm | X_mm | Y_mm | Z_mm | Material | Process | Qty
01_Main_shell | Core | tray | 230 | 330 | 128 | 3 | -115 | 0 | 0 | PC-ABS | Prototype print; production tooling review | 1
02_Service_door_frame | Core | ring | 224 | 324 | 5 | 14 | -112 | 3 | 129 | PC-ABS | Prototype print; production tooling review | 1
03_Upper_front_panel | Core | box | 194 | 106 | 3 | 0 | -97 | 207 | 130 | PC-ABS | Prototype print; production tooling review | 1
04_Lower_front_panel | Core | box | 194 | 67 | 3 | 0 | -97 | 17 | 130 | PC-ABS | Prototype print; production tooling review | 1
05_Optics_front_cover | Core | box | 194 | 93 | 3 | 0 | -97 | 114 | 130 | PC-ABS | Prototype print; production tooling review | 1
06_Input_shutter | Core | box | 154 | 25 | 3 | 0 | -70 | 86 | 131 | PC-ABS | Prototype print; production tooling review | 1
07_Door_EPDM_gasket | Core | ring | 224 | 324 | 1 | 3 | -112 | 3 | 128 | EPDM | Die cut | 1
08_Universal_mount_plate | Core | plate | 180 | 260 | 4 | 0 | -90 | 35 | -8 | 304 stainless steel | Laser cut / bend / machine | 1
09_Rear_standoff_L | Core | box | 12 | 245 | 4 | 0 | -84 | 43 | -4 | 304 stainless steel | Laser cut / bend / machine | 1
10_Rear_standoff_R | Core | box | 12 | 245 | 4 | 0 | 72 | 43 | -4 | 304 stainless steel | Laser cut / bend / machine | 1
11_Dry_electronics_tray | Core | tray | 196 | 96 | 66 | 3 | -98 | 224 | 12 | PC-ABS | Prototype print; production tooling review | 1
12_Dry_electronics_lid | Core | box | 190 | 90 | 2 | 0 | -95 | 227 | 78 | PC-ABS | Prototype print; production tooling review | 1
13_Controller_UNO_envelope | Core | box | 69 | 54 | 16 | 0 | -89 | 250 | 20 | COTS PCB envelope | Purchased envelope - VERIFY | 1
14_Dual_power_fuse_module | Core | box | 37 | 27 | 16 | 0 | -10 | 278 | 20 | COTS electrical envelope | Purchased envelope - VERIFY | 1
15_Display_bezel | Core | ring | 101 | 57 | 1 | 7 | -47 | 246 | 133 | PC-ABS | Prototype print; production tooling review | 1
16_Display_protective_window | Core | box | 86 | 42 | 1 | 0 | -39.5 | 253.5 | 133 | Polycarbonate | Prototype print; production tooling review | 1
17_QR_label_area | Core | box | 27 | 27 | 0.4 | 0 | 63 | 268 | 133 | Label | Prototype print; production tooling review | 1
18_Status_LED | Core | disk | 5 | 5 | 1 | 0 | -81 | 268 | 133 | COTS LED | Purchased envelope - VERIFY | 1
19_Buzzer_envelope | Core | disk | 14 | 14 | 7 | 0 | 65 | 292 | 30 | COTS buzzer | Purchased envelope - VERIFY | 1
20_Sealed_strip_cassette | Core | tray | 34 | 130 | 45 | 2 | -106 | 87 | 22 | Polypropylene | Prototype print; production tooling review | 1
21_Cassette_sealed_lid | Core | box | 30 | 126 | 2 | 0 | -104 | 89 | 67 | Polypropylene | Prototype print; production tooling review | 1
22_Optical_chamber | Core | tray | 158 | 59 | 66 | 2 | -64 | 145 | 22 | Black PC-ABS | Prototype print; production tooling review | 1
23_Optical_removable_lid | Core | box | 154 | 55 | 2 | 0 | -62 | 147 | 88 | Black PC-ABS | Prototype print; production tooling review | 1
24_Optical_insert_baffle | Core | ring | 148 | 49 | 7 | 3 | -59 | 150 | 79 | Black PC-ABS | Prototype print; production tooling review | 1
25_Strip_datum_carrier | Core | tray | 137 | 13 | 8 | 1 | -55 | 156 | 50 | Polypropylene | Prototype print; production tooling review | 1
26_Reagent_strip_envelope | Core | box | 125 | 5 | 0.5 | 0 | -49 | 160 | 52 | COTS strip envelope | Purchased envelope - VERIFY | 1
27_Scan_rail | Core | box | 142 | 6 | 6 | 0 | -57 | 191 | 43 | 304 stainless steel | Laser cut / bend / machine | 1
28_Optical_scan_carriage | Core | ring | 28 | 28 | 3 | 5 | -52 | 159 | 64 | Black PC-ABS | Prototype print; production tooling review | 1
29_RGB_sensor_envelope | Core | box | 21 | 21 | 5 | 0 | -48.5 | 162.5 | 67 | COTS PCB envelope | Purchased envelope - VERIFY | 1
30_Left_LED_bracket | Core | ring | 10 | 16 | 3 | 2 | -62 | 164 | 61 | Black PC-ABS | Prototype print; production tooling review | 1
31_Right_LED_bracket | Core | ring | 10 | 16 | 3 | 2 | -24 | 164 | 61 | Black PC-ABS | Prototype print; production tooling review | 1
32_Left_LED_envelope | Core | box | 6 | 8 | 2 | 0 | -60 | 168 | 64 | COTS LED | Purchased envelope - VERIFY | 1
33_Right_LED_envelope | Core | box | 6 | 8 | 2 | 0 | -22 | 168 | 64 | COTS LED | Purchased envelope - VERIFY | 1
34_Calibration_tile | Core | box | 8 | 8 | 1 | 0 | 83 | 158 | 54 | Ceramic reference placeholder | Prototype print; production tooling review | 1
35_Scan_motor_envelope | Core | box | 20 | 20 | 20 | 0 | 69 | 169 | 26 | COTS motor | Purchased envelope - VERIFY | 1
36_Lead_screw_envelope | Core | box | 132 | 3 | 3 | 0 | -54 | 188 | 52 | 304 stainless steel | Laser cut / bend / machine | 1
37_Sample_drawer_module | Core | tray | 154 | 24 | 51 | 2 | -70 | 89 | 78 | Polypropylene | Prototype print; production tooling review | 1
38_Wet_dry_barrier | Core | box | 198 | 3 | 112 | 0 | -99 | 219 | 8 | PC-ABS | Prototype print; production tooling review | 1
39_Drip_tray | Core | tray | 148 | 12 | 72 | 2 | -68 | 75 | 48 | Polypropylene | Prototype print; production tooling review | 1
40_Used_strip_waste_cartridge | Core | tray | 142 | 56 | 93 | 2 | -66 | 16 | 17 | Polypropylene | Prototype print; production tooling review | 1
41_Waste_transport_lid | Core | ring | 138 | 52 | 2 | 6 | -64 | 18 | 110 | Polypropylene | Prototype print; production tooling review | 1
42_Waste_closure_slide | Core | box | 125 | 38 | 1 | 0 | -57 | 25 | 112 | Polypropylene | Prototype print; production tooling review | 1
43_Cleaning_fluid_cartridge | Core | tray | 24 | 60 | 48 | 2 | 81 | 20 | 25 | Polypropylene | Prototype print; production tooling review | 1
44_Battery_tray | Battery | tray | 81 | 29 | 47 | 2 | -91 | 228 | 82 | PC-ABS | Prototype print; production tooling review | 1
45_Battery_protected_pack_envelope | Battery | box | 75 | 23 | 39 | 0 | -88 | 231 | 84 | COTS battery envelope | Purchased envelope - VERIFY | 1
46_DC_connector_bracket | DC | ring | 20 | 16 | 3 | 4 | 66 | 230 | 93 | PC-ABS | Prototype print; production tooling review | 1
47_DC_connector_envelope | DC | disk | 8 | 8 | 13 | 0 | 72 | 234 | 96 | COTS connector | Purchased envelope - VERIFY | 1
48_Cable_gland | Core | tube | 12 | 12 | 9 | 3 | 81 | 231 | 107 | COTS gland | Purchased envelope - VERIFY | 1
49_Strain_relief | Core | ring | 18 | 12 | 5 | 3 | 58 | 305 | 25 | EPDM | Die cut | 1
50_Cable_channel | Core | ring | 8 | 188 | 7 | 2 | 99 | 114 | 103 | PC-ABS | Prototype print; production tooling review | 1
51_Door_interlock | Core | box | 10 | 14 | 7 | 0 | 99 | 284 | 118 | COTS switch | Purchased envelope - VERIFY | 1
52_Cartridge_present_switch | Core | box | 8 | 10 | 6 | 0 | -76 | 53 | 97 | COTS switch | Purchased envelope - VERIFY | 1
53_Drip_overflow_sensor | Core | box | 12 | 6 | 2 | 0 | 63 | 77 | 90 | COTS PCB envelope | Purchased envelope - VERIFY | 1
54_Strip_jam_home_sensor | Core | box | 8 | 8 | 5 | 0 | 79 | 148 | 58 | COTS sensor | Purchased envelope - VERIFY | 1
55_Hinge_lower | Core | tube | 8 | 8 | 16 | 2 | -110 | 42 | 111 | 304 stainless steel | Laser cut / bend / machine | 1
56_Hinge_upper | Core | tube | 8 | 8 | 16 | 2 | -110 | 282 | 111 | 304 stainless steel | Laser cut / bend / machine | 1
57_Service_lock | Core | disk | 12 | 12 | 13 | 0 | 98 | 158 | 114 | COTS lock | Purchased envelope - VERIFY | 1
58_Tether_eye | Core | tube | 16 | 16 | 4 | 4 | 69 | 280 | -12 | 304 stainless steel | Laser cut / bend / machine | 1
59_M4_captive_fastener_0 | Core | disk | 4 | 4 | 7 | 0 | -80 | 47 | -7 | 304 stainless steel | Laser cut / bend / machine | 1
59_M4_captive_fastener_1 | Core | disk | 4 | 4 | 7 | 0 | 76 | 47 | -7 | 304 stainless steel | Laser cut / bend / machine | 1
59_M4_captive_fastener_2 | Core | disk | 4 | 4 | 7 | 0 | -80 | 279 | -7 | 304 stainless steel | Laser cut / bend / machine | 1
59_M4_captive_fastener_3 | Core | disk | 4 | 4 | 7 | 0 | 76 | 279 | -7 | 304 stainless steel | Laser cut / bend / machine | 1
Partition_adapter | Mount_Partition | plate | 180 | 260 | 4 | 0 | -90 | 35 | -16 | 304 stainless steel | Laser cut / bend / machine | 1
Rail_adapter | Mount_Rail | plate | 180 | 260 | 4 | 0 | -90 | 35 | -16 | 304 stainless steel | Laser cut / bend / machine | 1
Hook_adapter | Mount_Hook | plate | 180 | 260 | 4 | 0 | -90 | 35 | -16 | 304 stainless steel | Laser cut / bend / machine | 1
Pedestal_adapter | Mount_Pedestal | plate | 180 | 260 | 4 | 0 | -90 | 35 | -16 | 304 stainless steel | Laser cut / bend / machine | 1
Smooth_adapter | Mount_Smooth | plate | 180 | 260 | 4 | 0 | -90 | 35 | -16 | 304 stainless steel | Laser cut / bend / machine | 1
Magnetic_adapter | Mount_Magnetic | plate | 180 | 260 | 4 | 0 | -90 | 35 | -16 | 304 stainless steel | Laser cut / bend / machine | 1
Partition_fixed_jaw_0 | Mount_Partition | box | 40 | 35 | 4 | 0 | -20 | 60 | -20 | 304 stainless steel | Laser cut / bend / machine | 1
Partition_bridge_0 | Mount_Partition | box | 4 | 35 | 66 | 0 | -24 | 60 | -82 | 304 stainless steel | Laser cut / bend / machine | 1
Partition_moving_jaw_0 | Mount_Partition | box | 40 | 35 | 4 | 0 | -20 | 60 | -76 | 304 stainless steel | Laser cut / bend / machine | 1
Partition_pad_front_0 | Mount_Partition | box | 36 | 31 | 2 | 0 | -18 | 62 | -22 | EPDM | Die cut | 1
Partition_pad_rear_0 | Mount_Partition | box | 36 | 31 | 2 | 0 | -18 | 62 | -72 | EPDM | Die cut | 1
Partition_M8_screw_0 | Mount_Partition | disk | 8 | 8 | 16 | 0 | -4 | 73 | -90 | 304 stainless steel | Laser cut / bend / machine | 1
Rail_front_half_0 | Mount_Rail | half_front | 54 | 54 | 20 | 4 | -27 | 80 | -74 | 304 stainless steel | Laser cut / bend / machine | 1
Rail_rear_half_0 | Mount_Rail | half_rear | 54 | 54 | 20 | 4 | -27 | 80 | -74 | 304 stainless steel | Laser cut / bend / machine | 1
Rail_insert_front_32mm_0 | Mount_Rail | half_front | 46 | 46 | 20 | 7 | -23 | 80 | -70 | EPDM | Die cut | 1
Rail_insert_rear_32mm_0 | Mount_Rail | half_rear | 46 | 46 | 20 | 7 | -23 | 80 | -70 | EPDM | Die cut | 1
Rail_bridge_0 | Mount_Rail | box | 12 | 20 | 5 | 0 | -6 | 60 | -21 | 304 stainless steel | Laser cut / bend / machine | 1
Partition_fixed_jaw_1 | Mount_Partition | box | 40 | 35 | 4 | 0 | -20 | 250 | -20 | 304 stainless steel | Laser cut / bend / machine | 1
Partition_bridge_1 | Mount_Partition | box | 4 | 35 | 66 | 0 | -24 | 250 | -82 | 304 stainless steel | Laser cut / bend / machine | 1
Partition_moving_jaw_1 | Mount_Partition | box | 40 | 35 | 4 | 0 | -20 | 250 | -76 | 304 stainless steel | Laser cut / bend / machine | 1
Partition_pad_front_1 | Mount_Partition | box | 36 | 31 | 2 | 0 | -18 | 252 | -22 | EPDM | Die cut | 1
Partition_pad_rear_1 | Mount_Partition | box | 36 | 31 | 2 | 0 | -18 | 252 | -72 | EPDM | Die cut | 1
Partition_M8_screw_1 | Mount_Partition | disk | 8 | 8 | 16 | 0 | -4 | 263 | -90 | 304 stainless steel | Laser cut / bend / machine | 1
Rail_front_half_1 | Mount_Rail | half_front | 54 | 54 | 20 | 4 | -27 | 270 | -74 | 304 stainless steel | Laser cut / bend / machine | 1
Rail_rear_half_1 | Mount_Rail | half_rear | 54 | 54 | 20 | 4 | -27 | 270 | -74 | 304 stainless steel | Laser cut / bend / machine | 1
Rail_insert_front_32mm_1 | Mount_Rail | half_front | 46 | 46 | 20 | 7 | -23 | 270 | -70 | EPDM | Die cut | 1
Rail_insert_rear_32mm_1 | Mount_Rail | half_rear | 46 | 46 | 20 | 7 | -23 | 270 | -70 | EPDM | Die cut | 1
Rail_bridge_1 | Mount_Rail | box | 12 | 20 | 5 | 0 | -6 | 250 | -21 | 304 stainless steel | Laser cut / bend / machine | 1
Hook_top_bridge | Mount_Hook | box | 70 | 4 | 68 | 0 | -35 | 335 | -80 | 304 stainless steel | Laser cut / bend / machine | 1
Hook_front_drop | Mount_Hook | box | 70 | 75 | 4 | 0 | -35 | 260 | -20 | 304 stainless steel | Laser cut / bend / machine | 1
Hook_rear_drop | Mount_Hook | box | 70 | 60 | 4 | 0 | -35 | 275 | -80 | 304 stainless steel | Laser cut / bend / machine | 1
Hook_protective_pad | Mount_Hook | box | 66 | 2 | 53 | 0 | -33 | 333 | -73 | EPDM | Die cut | 1
Pedestal_ballast_base | Mount_Pedestal | box | 500 | 30 | 500 | 0 | -250 | -1030 | -245 | 304 stainless steel | Laser cut / bend / machine | 1
Pedestal_tower | Mount_Pedestal | box | 60 | 1200 | 6 | 0 | -30 | -1000 | -66 | 304 stainless steel | Laser cut / bend / machine | 1
Pedestal_head | Mount_Pedestal | box | 100 | 90 | 44 | 0 | -50 | 95 | -60 | PC-ABS | Prototype print; production tooling review | 1
Smooth_pad_0 | Mount_Smooth | box | 50 | 55 | 2 | 0 | -70 | 55 | -18 | COTS removable pad UNRATED | Purchased envelope - VERIFY | 1
Magnet_pot_0 | Mount_Magnetic | disk | 32 | 32 | 7 | 0 | -65 | 60 | -23 | COTS magnet UNRATED | Purchased envelope - VERIFY | 1
Smooth_pad_1 | Mount_Smooth | box | 50 | 55 | 2 | 0 | 20 | 55 | -18 | COTS removable pad UNRATED | Purchased envelope - VERIFY | 1
Magnet_pot_1 | Mount_Magnetic | disk | 32 | 32 | 7 | 0 | 33 | 60 | -23 | COTS magnet UNRATED | Purchased envelope - VERIFY | 1
Smooth_pad_2 | Mount_Smooth | box | 50 | 55 | 2 | 0 | -70 | 215 | -18 | COTS removable pad UNRATED | Purchased envelope - VERIFY | 1
Magnet_pot_2 | Mount_Magnetic | disk | 32 | 32 | 7 | 0 | -65 | 218 | -23 | COTS magnet UNRATED | Purchased envelope - VERIFY | 1
Smooth_pad_3 | Mount_Smooth | box | 50 | 55 | 2 | 0 | 20 | 215 | -18 | COTS removable pad UNRATED | Purchased envelope - VERIFY | 1
Magnet_pot_3 | Mount_Magnetic | disk | 32 | 32 | 7 | 0 | 33 | 218 | -23 | COTS magnet UNRATED | Purchased envelope - VERIFY | 1

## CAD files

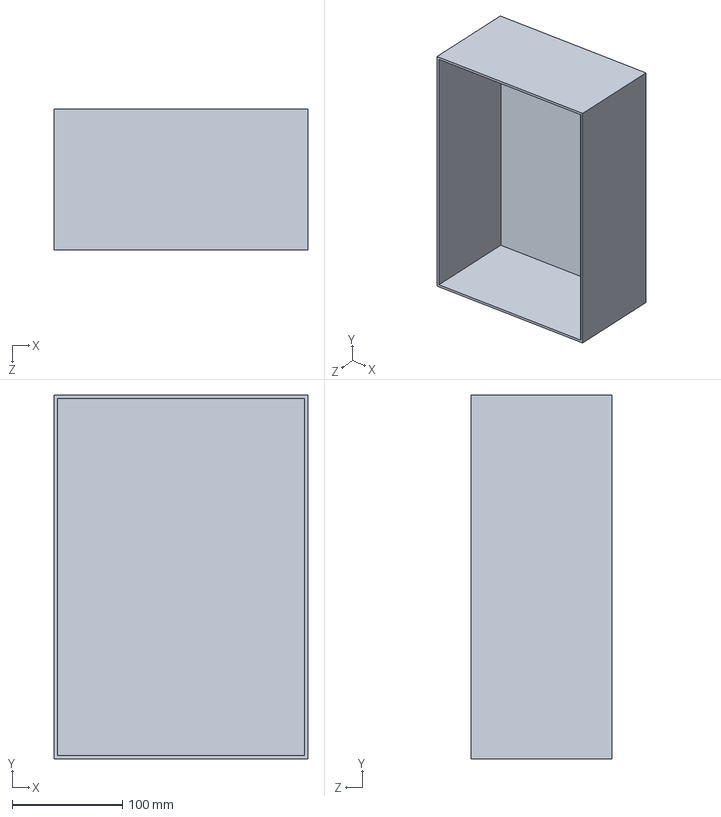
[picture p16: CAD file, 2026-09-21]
builds/20260913-163314/parts/01_Main_shell.SLDPRT
230.0 x 330.0 x 128.0 mm

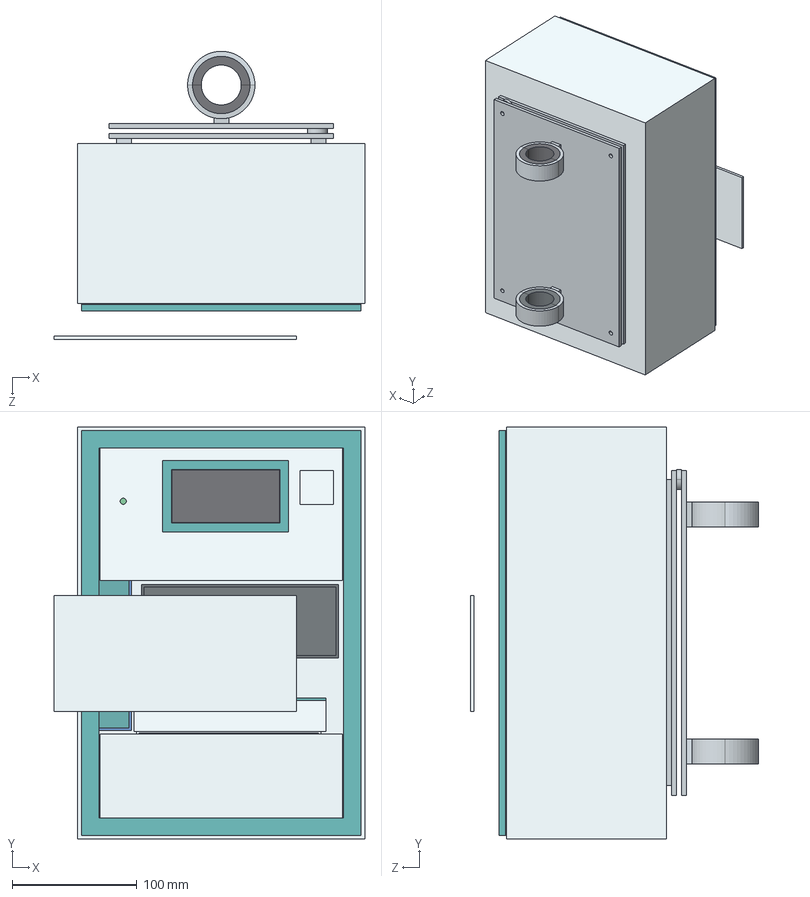
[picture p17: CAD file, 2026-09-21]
builds/20260913-163314/exports/step/Luma_Rail_Battery.step
248.9 x 330.0 x 231.0 mm
01_Main_shell
02_Service_door_frame
03_Upper_front_panel
04_Lower_front_panel
05_Optics_front_cover
06_Input_shutter
07_Door_EPDM_gasket
08_Universal_mount_plate
09_Rear_standoff_L
10_Rear_standoff_R
11_Dry_electronics_tray
12_Dry_electronics_lid
13_Controller_UNO_envelope
14_Dual_power_fuse_module
15_Display_bezel
16_Display_protective_window
17_QR_label_area
18_Status_LED
19_Buzzer_envelope
20_Sealed_strip_cassette
21_Cassette_sealed_lid
22_Optical_chamber
23_Optical_removable_lid
24_Optical_insert_baffle
25_Strip_datum_carrier
26_Reagent_strip_envelope
27_Scan_rail
28_Optical_scan_carriage
29_RGB_sensor_envelope
30_Left_LED_bracket
31_Right_LED_bracket
32_Left_LED_envelope
33_Right_LED_envelope
34_Calibration_tile
35_Scan_motor_envelope
36_Lead_screw_envelope
37_Sample_drawer_module
38_Wet_dry_barrier
39_Drip_tray
40_Used_strip_waste_cartridge
41_Waste_transport_lid
42_Waste_closure_slide
43_Cleaning_fluid_cartridge
44_Battery_tray
45_Battery_protected_pack_envelope
48_Cable_gland
49_Strain_relief
50_Cable_channel
51_Door_interlock
52_Cartridge_present_switch
53_Drip_overflow_sensor
54_Strip_jam_home_sensor
55_Hinge_lower
56_Hinge_upper
57_Service_lock
58_Tether_eye
59_M4_captive_fastener_0
59_M4_captive_fastener_1
59_M4_captive_fastener_2
59_M4_captive_fastener_3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

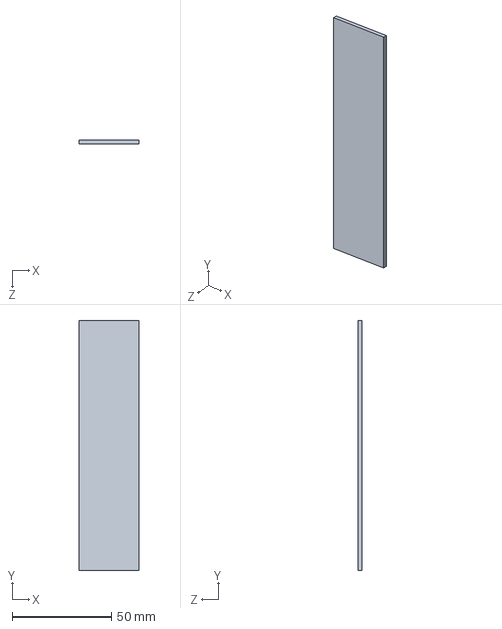
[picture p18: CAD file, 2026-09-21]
builds/20260913-163314/parts/21_Cassette_sealed_lid.SLDPRT
30.0 x 126.0 x 2.00 mm

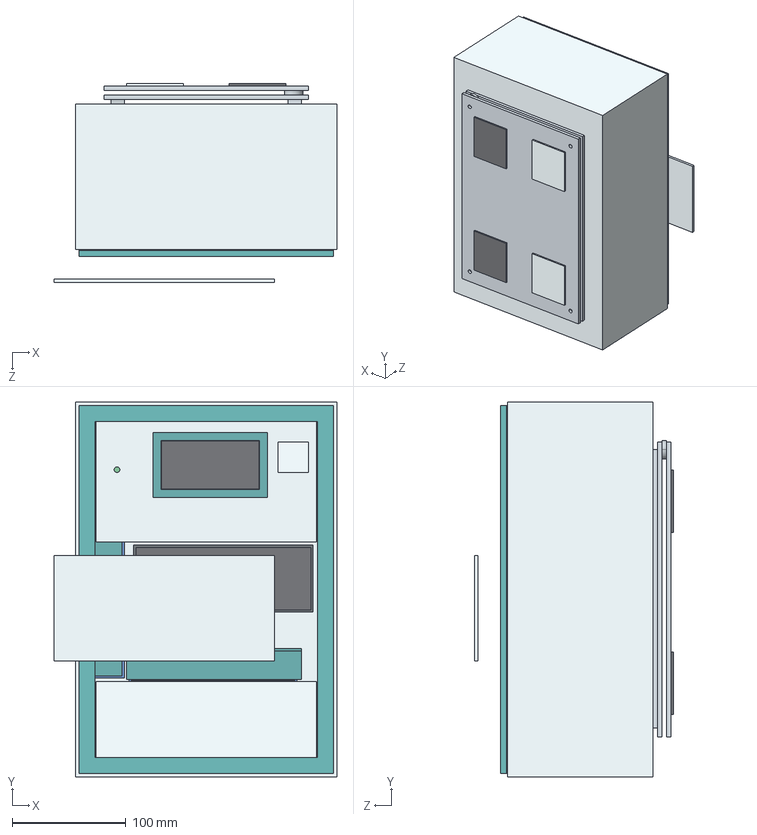
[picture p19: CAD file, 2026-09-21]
builds/20260913-163314/exports/step/Luma_Smooth_Battery.step
248.9 x 330.0 x 175.0 mm
01_Main_shell
02_Service_door_frame
03_Upper_front_panel
04_Lower_front_panel
05_Optics_front_cover
06_Input_shutter
07_Door_EPDM_gasket
08_Universal_mount_plate
09_Rear_standoff_L
10_Rear_standoff_R
11_Dry_electronics_tray
12_Dry_electronics_lid
13_Controller_UNO_envelope
14_Dual_power_fuse_module
15_Display_bezel
16_Display_protective_window
17_QR_label_area
18_Status_LED
19_Buzzer_envelope
20_Sealed_strip_cassette
21_Cassette_sealed_lid
22_Optical_chamber
23_Optical_removable_lid
24_Optical_insert_baffle
25_Strip_datum_carrier
26_Reagent_strip_envelope
27_Scan_rail
28_Optical_scan_carriage
29_RGB_sensor_envelope
30_Left_LED_bracket
31_Right_LED_bracket
32_Left_LED_envelope
33_Right_LED_envelope
34_Calibration_tile
35_Scan_motor_envelope
36_Lead_screw_envelope
37_Sample_drawer_module
38_Wet_dry_barrier
39_Drip_tray
40_Used_strip_waste_cartridge
41_Waste_transport_lid
42_Waste_closure_slide
43_Cleaning_fluid_cartridge
44_Battery_tray
45_Battery_protected_pack_envelope
48_Cable_gland
49_Strain_relief
50_Cable_channel
51_Door_interlock
52_Cartridge_present_switch
53_Drip_overflow_sensor
54_Strip_jam_home_sensor
55_Hinge_lower
56_Hinge_upper
57_Service_lock
58_Tether_eye
59_M4_captive_fastener_0
59_M4_captive_fastener_1
59_M4_captive_fastener_2
59_M4_captive_fastener_3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

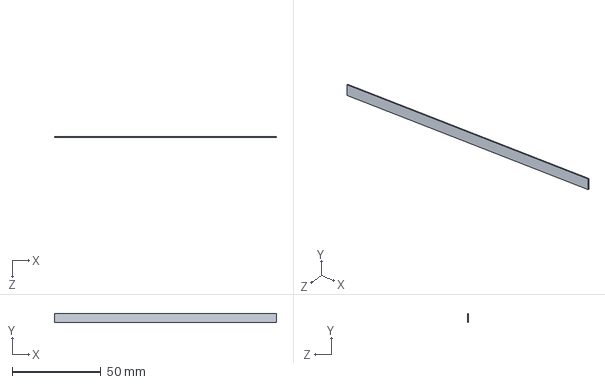
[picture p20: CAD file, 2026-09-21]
builds/20260913-163314/parts/26_Reagent_strip_envelope.SLDPRT
125.0 x 5.00 x 0.5 mm

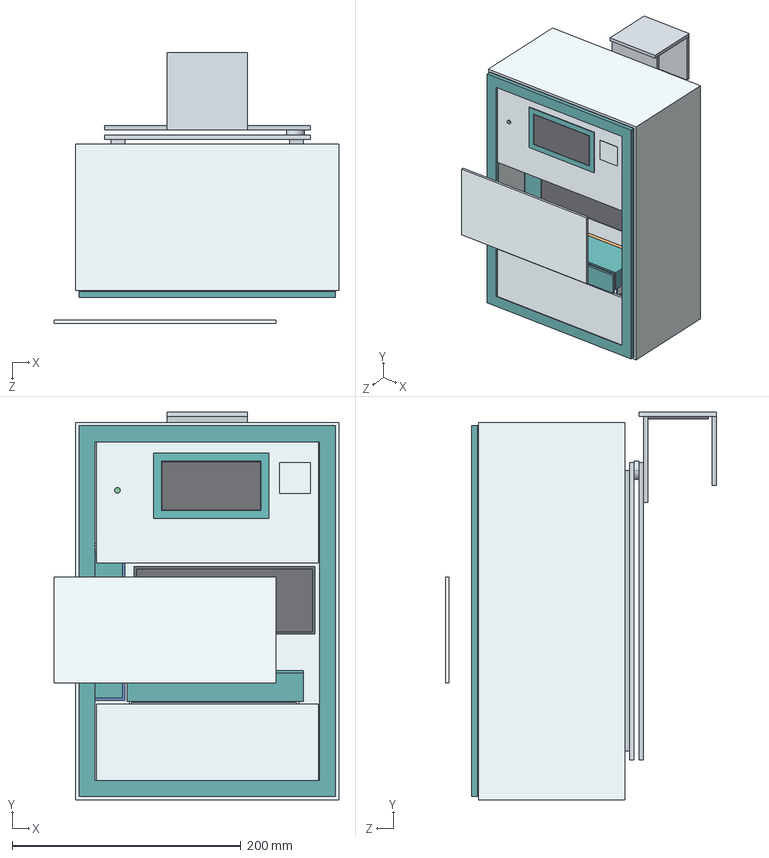
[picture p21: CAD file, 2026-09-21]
builds/20260913-163314/exports/step/Luma_Hook_DC.step
248.9 x 339.0 x 237.0 mm
01_Main_shell
02_Service_door_frame
03_Upper_front_panel
04_Lower_front_panel
05_Optics_front_cover
06_Input_shutter
07_Door_EPDM_gasket
08_Universal_mount_plate
09_Rear_standoff_L
10_Rear_standoff_R
11_Dry_electronics_tray
12_Dry_electronics_lid
13_Controller_UNO_envelope
14_Dual_power_fuse_module
15_Display_bezel
16_Display_protective_window
17_QR_label_area
18_Status_LED
19_Buzzer_envelope
20_Sealed_strip_cassette
21_Cassette_sealed_lid
22_Optical_chamber
23_Optical_removable_lid
24_Optical_insert_baffle
25_Strip_datum_carrier
26_Reagent_strip_envelope
27_Scan_rail
28_Optical_scan_carriage
29_RGB_sensor_envelope
30_Left_LED_bracket
31_Right_LED_bracket
32_Left_LED_envelope
33_Right_LED_envelope
34_Calibration_tile
35_Scan_motor_envelope
36_Lead_screw_envelope
37_Sample_drawer_module
38_Wet_dry_barrier
39_Drip_tray
40_Used_strip_waste_cartridge
41_Waste_transport_lid
42_Waste_closure_slide
43_Cleaning_fluid_cartridge
46_DC_connector_bracket
47_DC_connector_envelope
48_Cable_gland
49_Strain_relief
50_Cable_channel
51_Door_interlock
52_Cartridge_present_switch
53_Drip_overflow_sensor
54_Strip_jam_home_sensor
55_Hinge_lower
56_Hinge_upper
57_Service_lock
58_Tether_eye
59_M4_captive_fastener_0
59_M4_captive_fastener_1
59_M4_captive_fastener_2
59_M4_captive_fastener_3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

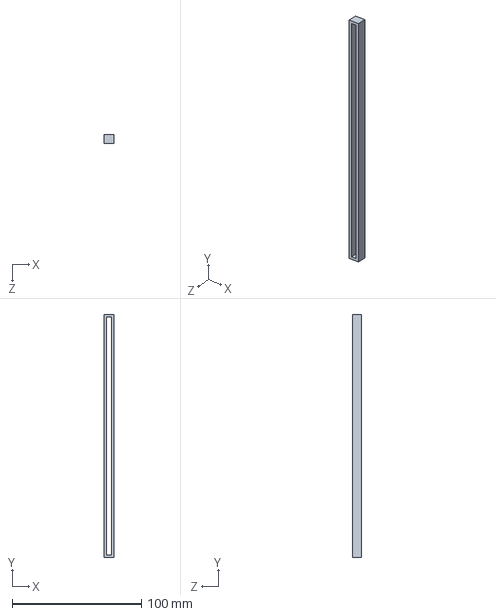
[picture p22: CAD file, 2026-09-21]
builds/20260913-163314/parts/50_Cable_channel.SLDPRT
8.00 x 188.0 x 7.00 mm

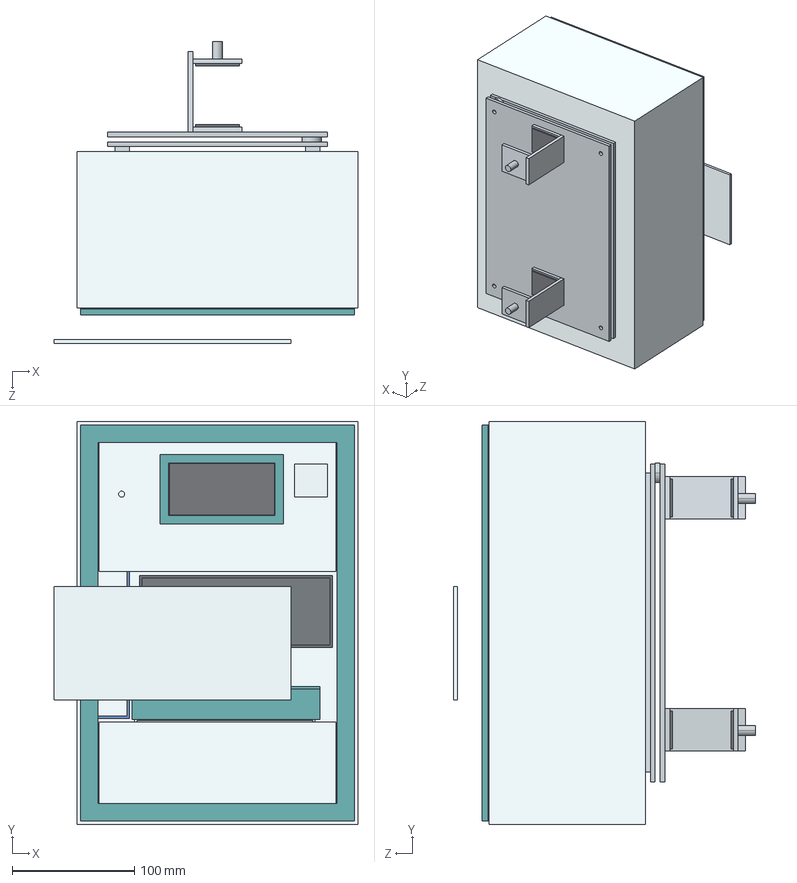
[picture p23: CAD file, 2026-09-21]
builds/20260913-163314/exports/step/Luma_Partition_Battery.step
248.9 x 330.0 x 247.0 mm
01_Main_shell
02_Service_door_frame
03_Upper_front_panel
04_Lower_front_panel
05_Optics_front_cover
06_Input_shutter
07_Door_EPDM_gasket
08_Universal_mount_plate
09_Rear_standoff_L
10_Rear_standoff_R
11_Dry_electronics_tray
12_Dry_electronics_lid
13_Controller_UNO_envelope
14_Dual_power_fuse_module
15_Display_bezel
16_Display_protective_window
17_QR_label_area
18_Status_LED
19_Buzzer_envelope
20_Sealed_strip_cassette
21_Cassette_sealed_lid
22_Optical_chamber
23_Optical_removable_lid
24_Optical_insert_baffle
25_Strip_datum_carrier
26_Reagent_strip_envelope
27_Scan_rail
28_Optical_scan_carriage
29_RGB_sensor_envelope
30_Left_LED_bracket
31_Right_LED_bracket
32_Left_LED_envelope
33_Right_LED_envelope
34_Calibration_tile
35_Scan_motor_envelope
36_Lead_screw_envelope
37_Sample_drawer_module
38_Wet_dry_barrier
39_Drip_tray
40_Used_strip_waste_cartridge
41_Waste_transport_lid
42_Waste_closure_slide
43_Cleaning_fluid_cartridge
44_Battery_tray
45_Battery_protected_pack_envelope
48_Cable_gland
49_Strain_relief
50_Cable_channel
51_Door_interlock
52_Cartridge_present_switch
53_Drip_overflow_sensor
54_Strip_jam_home_sensor
55_Hinge_lower
56_Hinge_upper
57_Service_lock
58_Tether_eye
59_M4_captive_fastener_0
59_M4_captive_fastener_1
59_M4_captive_fastener_2
59_M4_captive_fastener_3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

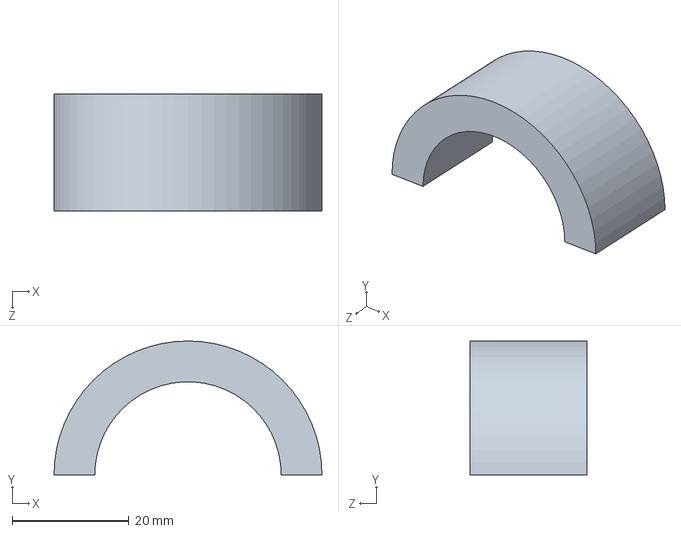
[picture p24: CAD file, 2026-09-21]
builds/20260913-163314/parts/Rail_insert_front_32mm_0.SLDPRT
46.0 x 23.0 x 20.0 mm

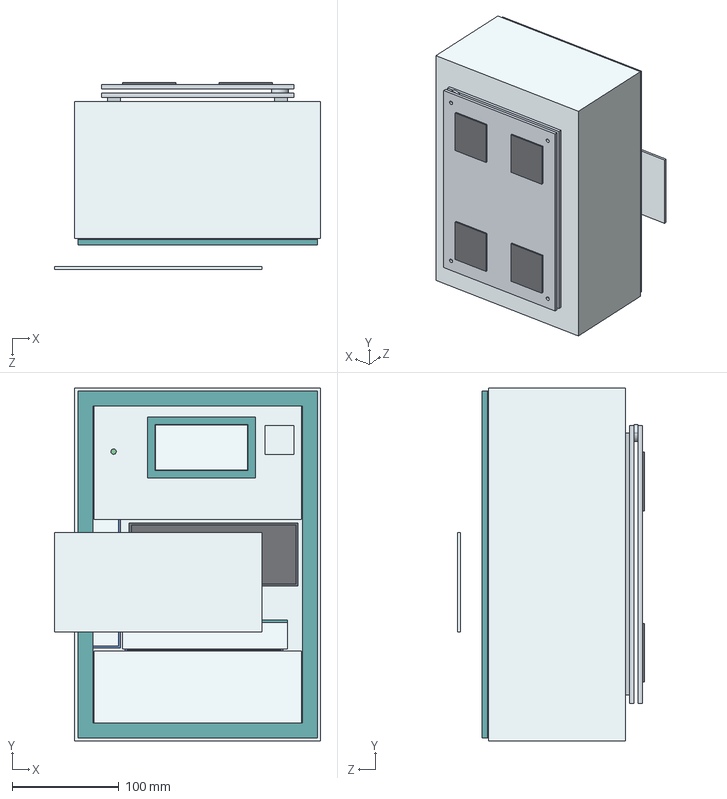
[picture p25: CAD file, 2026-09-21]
builds/20260913-163314/exports/step/Luma_Smooth_DC.step
248.9 x 330.0 x 175.0 mm
01_Main_shell
02_Service_door_frame
03_Upper_front_panel
04_Lower_front_panel
05_Optics_front_cover
06_Input_shutter
07_Door_EPDM_gasket
08_Universal_mount_plate
09_Rear_standoff_L
10_Rear_standoff_R
11_Dry_electronics_tray
12_Dry_electronics_lid
13_Controller_UNO_envelope
14_Dual_power_fuse_module
15_Display_bezel
16_Display_protective_window
17_QR_label_area
18_Status_LED
19_Buzzer_envelope
20_Sealed_strip_cassette
21_Cassette_sealed_lid
22_Optical_chamber
23_Optical_removable_lid
24_Optical_insert_baffle
25_Strip_datum_carrier
26_Reagent_strip_envelope
27_Scan_rail
28_Optical_scan_carriage
29_RGB_sensor_envelope
30_Left_LED_bracket
31_Right_LED_bracket
32_Left_LED_envelope
33_Right_LED_envelope
34_Calibration_tile
35_Scan_motor_envelope
36_Lead_screw_envelope
37_Sample_drawer_module
38_Wet_dry_barrier
39_Drip_tray
40_Used_strip_waste_cartridge
41_Waste_transport_lid
42_Waste_closure_slide
43_Cleaning_fluid_cartridge
46_DC_connector_bracket
47_DC_connector_envelope
48_Cable_gland
49_Strain_relief
50_Cable_channel
51_Door_interlock
52_Cartridge_present_switch
53_Drip_overflow_sensor
54_Strip_jam_home_sensor
55_Hinge_lower
56_Hinge_upper
57_Service_lock
58_Tether_eye
59_M4_captive_fastener_0
59_M4_captive_fastener_1
59_M4_captive_fastener_2
59_M4_captive_fastener_3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

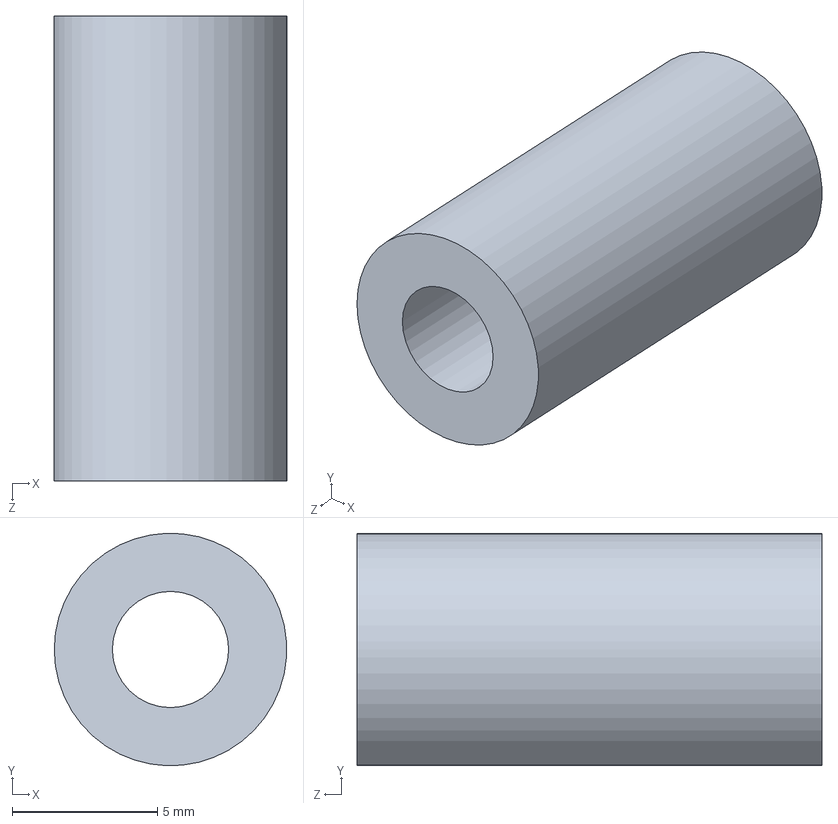
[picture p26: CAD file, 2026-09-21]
builds/20260913-163314/parts/56_Hinge_upper.SLDPRT
8.00 x 8.00 x 16.0 mm

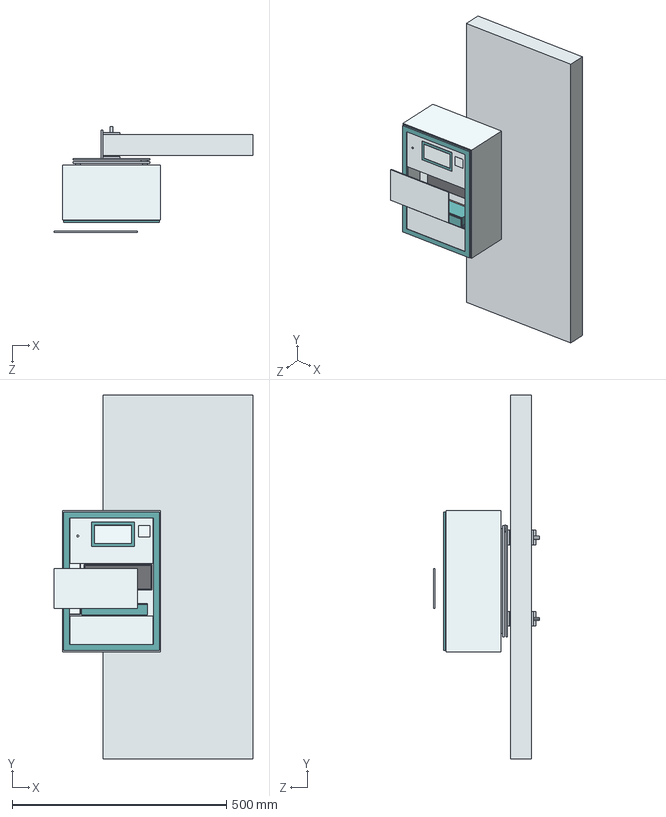
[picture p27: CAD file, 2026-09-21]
builds/20260913-163314/exports/step/Luma_Installed_Partition.step
463.9 x 850.0 x 247.0 mm
01_Main_shell
02_Service_door_frame
03_Upper_front_panel
04_Lower_front_panel
05_Optics_front_cover
06_Input_shutter
07_Door_EPDM_gasket
08_Universal_mount_plate
09_Rear_standoff_L
10_Rear_standoff_R
11_Dry_electronics_tray
12_Dry_electronics_lid
13_Controller_UNO_envelope
14_Dual_power_fuse_module
15_Display_bezel
16_Display_protective_window
17_QR_label_area
18_Status_LED
19_Buzzer_envelope
20_Sealed_strip_cassette
21_Cassette_sealed_lid
22_Optical_chamber
23_Optical_removable_lid
24_Optical_insert_baffle
25_Strip_datum_carrier
26_Reagent_strip_envelope
27_Scan_rail
28_Optical_scan_carriage
29_RGB_sensor_envelope
30_Left_LED_bracket
31_Right_LED_bracket
32_Left_LED_envelope
33_Right_LED_envelope
34_Calibration_tile
35_Scan_motor_envelope
36_Lead_screw_envelope
37_Sample_drawer_module
38_Wet_dry_barrier
39_Drip_tray
40_Used_strip_waste_cartridge
41_Waste_transport_lid
42_Waste_closure_slide
43_Cleaning_fluid_cartridge
46_DC_connector_bracket
47_DC_connector_envelope
48_Cable_gland
49_Strain_relief
50_Cable_channel
51_Door_interlock
52_Cartridge_present_switch
53_Drip_overflow_sensor
54_Strip_jam_home_sensor
55_Hinge_lower
56_Hinge_upper
57_Service_lock
58_Tether_eye
59_M4_captive_fastener_0
59_M4_captive_fastener_1
59_M4_captive_fastener_2
59_M4_captive_fastener_3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

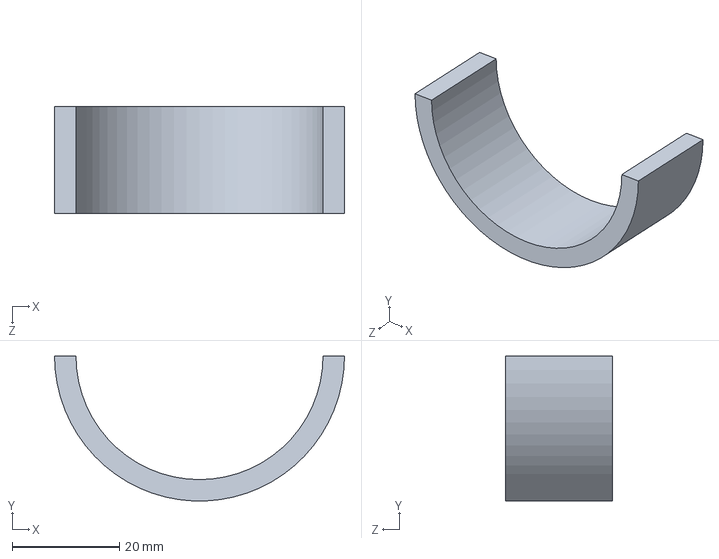
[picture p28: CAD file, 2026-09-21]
builds/20260913-163314/parts/Rail_rear_half_0.SLDPRT
54.0 x 27.0 x 20.0 mm

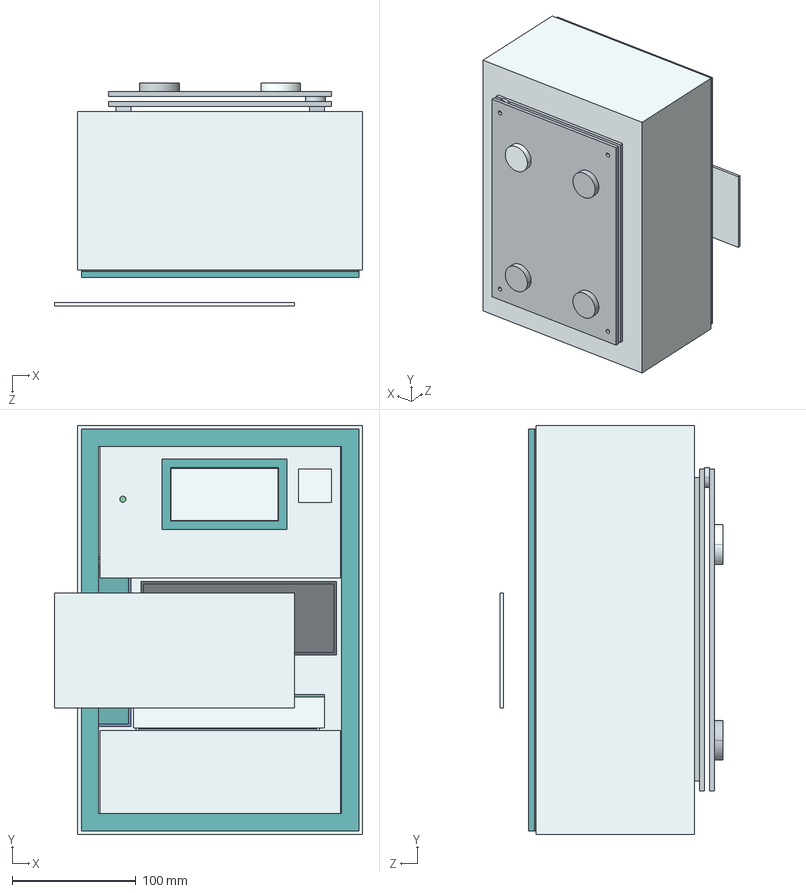
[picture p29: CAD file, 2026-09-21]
builds/20260913-163314/exports/step/Luma_Magnetic_DC.step
248.9 x 330.0 x 180.0 mm
01_Main_shell
02_Service_door_frame
03_Upper_front_panel
04_Lower_front_panel
05_Optics_front_cover
06_Input_shutter
07_Door_EPDM_gasket
08_Universal_mount_plate
09_Rear_standoff_L
10_Rear_standoff_R
11_Dry_electronics_tray
12_Dry_electronics_lid
13_Controller_UNO_envelope
14_Dual_power_fuse_module
15_Display_bezel
16_Display_protective_window
17_QR_label_area
18_Status_LED
19_Buzzer_envelope
20_Sealed_strip_cassette
21_Cassette_sealed_lid
22_Optical_chamber
23_Optical_removable_lid
24_Optical_insert_baffle
25_Strip_datum_carrier
26_Reagent_strip_envelope
27_Scan_rail
28_Optical_scan_carriage
29_RGB_sensor_envelope
30_Left_LED_bracket
31_Right_LED_bracket
32_Left_LED_envelope
33_Right_LED_envelope
34_Calibration_tile
35_Scan_motor_envelope
36_Lead_screw_envelope
37_Sample_drawer_module
38_Wet_dry_barrier
39_Drip_tray
40_Used_strip_waste_cartridge
41_Waste_transport_lid
42_Waste_closure_slide
43_Cleaning_fluid_cartridge
46_DC_connector_bracket
47_DC_connector_envelope
48_Cable_gland
49_Strain_relief
50_Cable_channel
51_Door_interlock
52_Cartridge_present_switch
53_Drip_overflow_sensor
54_Strip_jam_home_sensor
55_Hinge_lower
56_Hinge_upper
57_Service_lock
58_Tether_eye
59_M4_captive_fastener_0
59_M4_captive_fastener_1
59_M4_captive_fastener_2
59_M4_captive_fastener_3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

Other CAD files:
builds/20260913-163314/Luma_Exploded.SLDASM
builds/20260913-163314/Luma_Retrofit.SLDASM
builds/20260913-163314/Part59.SLDPRT
builds/20260913-163314/Part21.SLDPRT
builds/20260913-163314/Luma_GA.SLDDRW
builds/20260913-163314/exports/step/Luma_Hook_Battery.step
builds/20260913-163314/exports/step/Luma_Installed_Pedestal.step
builds/20260913-163314/exports/step/Luma_Installed_Rail.step
builds/20260913-163314/exports/step/Luma_Installed_Smooth.step
builds/20260913-163314/exports/step/Luma_Magnetic_Battery.step
builds/20260913-163314/exports/step/Luma_Partition_DC.step
builds/20260913-163314/exports/step/Luma_Pedestal_Battery.step
builds/20260913-163314/exports/step/Luma_Pedestal_DC.step
builds/20260913-163314/exports/step/Luma_Rail_DC.step
builds/20260913-163314/exports/step/Luma_Service_Open.step
builds/20260913-163314/exports/stl/01_Main_shell.stl
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

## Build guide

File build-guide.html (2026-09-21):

Build guide · Rev A

# How to build the Luma urine test strip reader

The complete parts list with specifications, where every component goes, and how to put it together. All sizes and positions come straight from the CAD model (build 20260913-163314).

Parts listAssembly stepsWiring

38purchased items (all versions)

293D-printed parts

27stainless-steel parts

11EPDM rubber parts

Read this first. Luma Rev A is an engineering prototype, not a medical device or a finished product. The CAD reserves space for each purchased component (an “envelope”); the parts suggested here fit those envelopes, but the scan drive is still schematic, clamp hardware needs detailing, and no firmware is included yet. Treat this as a guide for building and testing a prototype.

## Contents

1. Where everything goes
2. Purchased components
3. Parts not in the CAD
4. 3D-printed parts
5. Stainless-steel parts
6. EPDM rubber parts
7. Mount kits
8. Tools
9. Assembly, step by step
10. Wiring
11. First power-up and testing
12. Servicing
13. Budget

## Where everything goes

Positions are in millimetres from the enclosure’s own origin: x runs across (0 = centre, negative = left when you face the front), y runs up from the bottom of the case, and z runs forward from the back wall. The front panels sit at z ≈ 130 mm. Numbers match the part numbers in the tables and the CAD files.

### Where does the Arduino go?

In the dry electronics compartment at the top of the enclosure, above the wet/dry barrier. The Uno stands upright against the back wall of the tray in the upper-left corner (x −89…−20, y 250…304, z 20…36 mm), with the fuse module to its right and the buzzer at the top right. Show the Arduino in 3D ↗

Front view: modules (front panels removed)

1. 11 Dry electronics tray
2. 38 Wet/dry barrier
3. 20 Clean strip cassette
4. 22 Optical chamber
5. 37 Sample drawer
6. 39 Drip tray
7. 40 Waste cartridge
8. 43 Cleaning-fluid cartridge
9. 50 Cable channel
10. 44 Battery tray (battery version)

Front view: electronics and sensors

1. 16 Display window (display behind)
2. 45 Battery pack (battery version)
3. 13 Arduino Uno
4. 14 Fuse module
5. 19 Buzzer
6. 18 Status LED
7. 47 DC jack
8. 48 Cable gland
9. 51 Door interlock
10. 29 RGB sensor (TCS34725)
11. 32 Left LED
12. 33 Right LED
13. 35 Scan motor
14. 54 Home / jam sensor
15. 34 Reference tile
16. 57 Service lock
17. 52 Cartridge sensor
18. 53 Overflow sensor

Side view: depth (back on the left)

1. 08 Mounting plate
2. 11 Dry electronics tray
3. 12 Dry-tray lid
4. 13 Arduino Uno
5. 44 Battery tray (battery version)
6. 38 Wet/dry barrier
7. 22 Optical chamber
8. 26 Test strip
9. 29 RGB sensor
10. 37 Sample drawer
11. 40 Waste cartridge
12. 03 Upper front panel
13. 02 Door frame

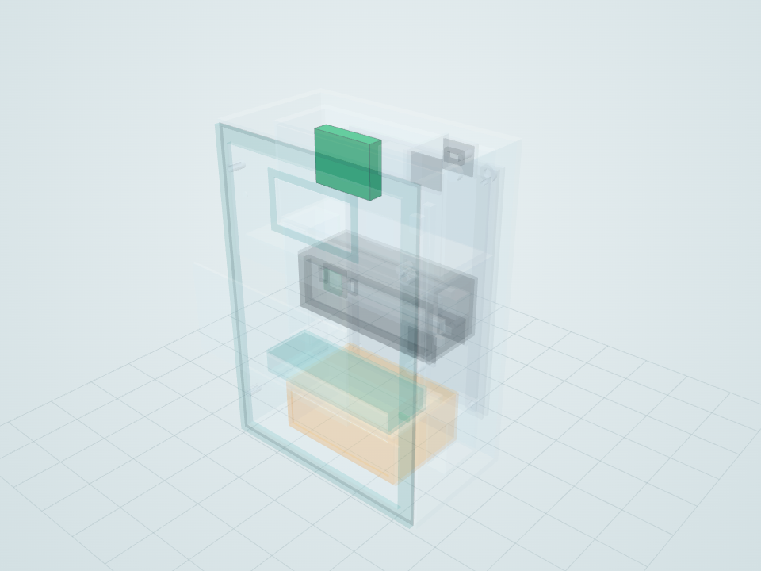
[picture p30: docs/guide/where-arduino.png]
The Arduino Uno highlighted in green in the upper-left of the Luma reader's dry electronics compartment


The Arduino Uno (green) inside the enclosure. Dashed outlines in the diagrams are battery-version parts.

## Purchased components

Each part must fit the envelope the CAD reserves for it (W × H × D). Where a part is named, it is one that fits; equivalents are fine if they fit and match the specification. The # column is the part number used in the CAD files and the diagrams.

### Controller and power

# | Component | Qty | Specification | CAD envelope | Where it goes

13 | Arduino Uno R3 | 1 | ATmega328P, 5 V logic, 68.6 × 53.4 mm board with 4 × Ø3.2 mm holes. The Uno R4 Minima/WiFi share the footprint.Keep the USB-B port reachable for programming; the CAD reserves no cable path for it. | 69 × 54 × 16 mm | Dry electronics tray, upper left. Stands upright against the tray’s back wall on 5 mm M3 standoffs, headers facing the front.x −89…−20, y 250…304, z 20…36 mm | 3D ↗
14 | Dual fuse holder board | 1 | Two 5 × 20 mm fuse holders on one board. Suggested: F1 input 1 A time-lag, F2 motor branch 0.5 A.Size the fuses to your measured load and wire gauge. | 37 × 27 × 16 mm | Dry electronics tray, top, right of the Arduino.x −10…27, y 278…305, z 20…36 mm | 3D ↗
47 | DC barrel jack (DC version) | 1 | Panel-mount 5.5 × 2.1 mm jack, rated ≥ 2 A, compact body.Supply: 9 V DC, ≥ 1 A, centre-positive plug-in adapter (SELV) from an existing safe socket. The cable path through the enclosure wall still has to be detailed. | 8 × 8 × 13 mm | Upper right, on bracket 46, behind the upper front panel.x 72…80, y 234…242, z 96…109 mm | 3D ↗
48 | Cable gland | 1 | M12 × 1.5 nylon cable gland, IP68, for cable Ø3–6.5 mm. | 12 × 12 × 9 mm | Upper right, next to the DC jack.x 81…93, y 231…243, z 107…116 mm | 3D ↗
45 | 2S Li-ion battery pack with protection (battery version) | 1 | 7.4 V nominal, 8.4 V full: 2 × 18650 cells in 2S1P with a protection board (BMS), about 70 × 37 × 19 mm.Charge outside the enclosure with a matching 2S (8.4 V) charger. The energy budget still has to be measured. | 75 × 23 × 39 mm | In the battery tray (44), upper left, in front of the dry-compartment lid.x −88…−13, y 231…254, z 84…123 mm | 3D ↗

### Optics and sensing

# | Component | Qty | Specification | CAD envelope | Where it goes

29 | TCS34725 RGB colour sensor breakout | 1 | I²C colour sensor (address 0x29) on a 3.3–5 V board with regulator, about 20 × 20 mm (e.g. Adafruit 1334 or equivalent).Ground the board’s LED pin so its own LED stays off and only the two angled LEDs light the pads. Board sizes vary; check it fits the envelope. | 21 × 21 × 5 mm | Centre of the scan carriage (28), facing back onto the test strip.x −48.5…−27.5, y 162.5…183.5, z 67…72 mm | 3D ↗
32, 33 | White LEDs | 2 | White SMD LED on a small carrier board, about 20 mA; high colour rendering (CRI ≥ 80) recommended.Aim them 30–60° to the strip to avoid glare; the best angle still has to be found on a bench jig. | 6 × 8 × 2 mm | On brackets 30 and 31 either side of the sensor.x −60…−16, y 168…176, z 64…66 mm | 3D ↗
35 | Micro linear stepper motor | 1 | 15 mm-class 2-phase bipolar stepper (about 5 V) with an M3 lead screw and nut, ≥ 100 mm stroke; body within the envelope.The scan drive is schematic in Rev A: the motor, lead screw and carriage are not yet coupled in the CAD. | 20 × 20 × 20 mm | Right end of the optical chamber.x 69…89, y 169…189, z 26…46 mm | 3D ↗
36 | M3 lead screw | 1 | 3 mm lead screw, about 132 mm long; normally supplied with the micro stepper. | 132 × 3 × 3 mm | Along the top of the optical chamber, beside the scan rail.x −54…78, y 188…191, z 52…55 mm | 3D ↗
54 | Carriage home / strip-jam sensor | 1 | Reflective optical sensor (e.g. QRE1113) or a Hall sensor, on a board within the envelope. | 8 × 8 × 5 mm | Right end of the optical chamber.x 79…87, y 148…156, z 58…63 mm | 3D ↗
34 | White reference tile | 1 | 8 × 8 × 1 mm white ceramic (or PTFE) reference for calibration. | 8 × 8 × 1 mm | Right end of the scan travel, level with the test strip.x 83…91, y 158…166, z 54…55 mm | 3D ↗

### Switches, safety and interface

# | Component | Qty | Specification | CAD envelope | Where it goes

51 | Door interlock switch | 1 | Ultra-subminiature snap-action switch, e.g. Omron D2F series (12.8 × 5.8 × 6.5 mm).Wire it so an open door stops all motion. | 10 × 14 × 7 mm | Upper right, just behind the door frame.x 99…109, y 284…298, z 118…125 mm | 3D ↗
52 | Cartridge-present sensor | 1 | Miniature switch, or a Hall-effect sensor with a small magnet on the cartridge. | 8 × 10 × 6 mm | Lower left, beside the waste cartridge.x −76…−68, y 53…63, z 97…103 mm | 3D ↗
53 | Drip-overflow sensor | 1 | Two-electrode conductive probe (or capacitive pad) on a small custom PCB. | 12 × 6 × 2 mm | Lower right, at the drip tray.x 63…75, y 77…83, z 90…92 mm | 3D ↗
18 | Status LED | 1 | 5 mm green LED with a 330 Ω series resistor.Drill a Ø5 mm hole in the upper front panel; it is not cut in the CAD. | 5 × 5 × 1 mm | Front face of the upper panel, left of the display.x −81…−76, y 268…273, z 133…134 mm | 3D ↗
19 | Piezo buzzer | 1 | Passive piezo buzzer, driven with tone(). | 14 × 14 × 7 mm | Dry electronics tray, top right.x 65…79, y 292…306, z 30…37 mm | 3D ↗
57 | Service lock | 1 | Compact quarter-turn cam lock. | 12 × 12 × 13 mm | Right edge of the door, mid height.x 98…110, y 158…170, z 114…127 mm | 3D ↗
16 | Display window | 1 | 1 mm clear polycarbonate sheet, laser-cut. | 86 × 42 × 1 mm | Front of the upper panel, over the 84 × 40 mm display opening.x −39.5…46.5, y 253.5…295.5, z 133…134 mm | 3D ↗
17 | QR label | 1 | Printed vinyl label, 27 × 27 mm. | 27 × 27 × 0.4 mm | Front of the upper panel, right of the display.x 63…90, y 268…295, z 133…133.4 mm | 3D ↗

### Consumables

# | Component | Qty | Specification | CAD envelope | Where it goes

26 | Urinalysis reagent test strips | 1 | 10–14 parameter urine test strips; the CAD assumes a 125 × 5 × 0.5 mm strip (14-pad concept).Measure your supplier’s strip (length with handle, pad pitch, reaction times) before finalising the carrier. | 125 × 5 × 0.5 mm | Held by the strip datum carrier (25) under the sensor.x −49…76, y 160…165, z 52…52.5 mm | 3D ↗

### Hardware

# | Component | Qty | Specification | CAD envelope | Where it goes

55, 56 | Door hinges | 2 | Stainless hinge knuckles, Ø8 mm × 16 mm, Ø4 mm pin. | 8 × 8 × 16 mm | Left edge of the door, near the bottom and top.x −110…−102, y 42…290, z 111…127 mm | 3D ↗
58 | Tether eye | 1 | Stainless ring, Ø16 mm outside, Ø8 mm hole, 4 mm thick.Anchor point for a safety tether (required for smooth-surface and magnetic mounts). | 16 × 16 × 4 mm | Back of the enclosure, upper right.x 69…85, y 280…296, z −12…−8 mm | 3D ↗
59, 59, 59, 59 | M4 captive screws | 4 | M4 captive panel screws, A2 stainless, length to suit the plate stack. | 4 × 4 × 7 mm | Back of the enclosure, through the mounting plate at x ±78 mm, y 49 and 281 mm.x −80…80, y 47…283, z −7…0 mm | 3D ↗

### Mount hardware

# | Component | Qty | Specification | CAD envelope | Where it goes

— | Partition clamp screws | 2 | M8 stainless clamp screws with knobs, long enough for 12–50 mm panels (the CAD shows a 16 mm stub). | 8 × 8 × 16 mm | One per partition clamp, through the moving jaw.x −4…4, y 73…271, z −90…−74 mm | 3D ↗
— | Pot magnets (magnetic mount) | 4 | Ø32 × 7 mm neodymium pot magnets with threaded boss.Reserved concept, not approved: holding force must be verified and an independent tether fitted. | 32 × 32 × 7 mm | Four corners of the magnetic adapter plate.x −65…65, y 60…250, z −23…−16 mm | 3D ↗
— | Removable mounting pads (smooth-surface mount) | 4 | 50 × 55 × 2 mm rated removable pads for glass or glazed tile.Reserved concept, not approved: use a rated product and an independent tether. | 50 × 55 × 2 mm | Four corners of the smooth-surface adapter plate.x −70…70, y 55…270, z −18…−16 mm | 3D ↗

## Parts not in the CAD

The model doesn’t include these, but you need them for a working prototype. They are suggestions that fit the free space.

Item | Qty | Specification | Where it goes
16×2 character LCD with I²C backpack | 1 | LCD1602 with PCF8574 backpack (I²C address 0x27 or 0x3F), board 80 × 36 mm. | Behind the 84 × 40 mm opening in the upper front panel (03), under the window (16). In the battery version, check it clears the battery tray (top edge at y 257 mm).
Stepper motor driver | 1 | DRV8834 low-voltage stepper driver carrier (2.5–10.8 V motor supply). Set its current limit to the motor’s rating. | Dry electronics tray, in the free area right of the fuse module (about x 30…95, y 225…290 mm).
Reverse-polarity diode | 1 | 3 A Schottky diode (e.g. 1N5822 or SS34) in series with the supply input. | Dry electronics tray, at the fuse module input.
Resistors (¼ W) | 5 | 2 × 150 Ω (white LEDs), 1 × 330 Ω (status LED), 2 × 10 kΩ (battery voltage divider, battery version). | On the wiring harness or a small perfboard in the dry tray.
Wire, connectors and heat-shrink | — | 22 AWG for power, 26 AWG for signals; JST-XH connectors so each module can be unplugged for service. | Routed through the cable channel (50) on the right side, above liquid-holding areas.
Standoffs and screws for the Arduino | 4 + 8 | M3 × 5 mm nylon standoffs, M3 × 6 mm screws. | Dry tray back wall.
Heat-set threaded inserts | 4 + as needed | M4 brass inserts for the four mounting-plate screws; M3 inserts for lids and brackets. | Back wall of the main shell (01) at x ±78 mm, y 49 and 281 mm; lids and brackets.
Power supply or charger | 1 | DC version: 9 V DC, ≥ 1 A, centre-positive adapter. Battery version: 2S (8.4 V) Li-ion charger. | Outside the enclosure.
Seals and feed-throughs | — | Gaskets or sealant where cables pass the wet/dry barrier (38) and dry-tray lid (12). | Barrier and dry compartment.

## 3D-printed parts

Designed as PC-ABS prototype prints, in black PC-ABS for the optics and polypropylene for parts that touch liquid. STL files for all of them are in exports/stl (https://github.com/tamnisan/luma/tree/main/builds/20260913-163314/exports/stl).

# | Part | Qty | Material | Size (W × H × D) | Notes

01 | Main shellAll versions | 1 | PC-ABS | 230 × 330 × 128 mmwall 3 mm | Large: needs a build volume of at least 330 mm in one axis, or split and bond. | 3D ↗
02 | Service door frameAll versions | 1 | PC-ABS | 224 × 324 × 5 mmwall 14 mm | Large: needs a build volume of at least 330 mm in one axis, or split and bond. | 3D ↗
03 | Upper front panelAll versions | 1 | PC-ABS | 194 × 106 × 3 mm | | 3D ↗
04 | Lower front panelAll versions | 1 | PC-ABS | 194 × 67 × 3 mm | | 3D ↗
05 | Optics front coverAll versions | 1 | PC-ABS | 194 × 93 × 3 mm | | 3D ↗
06 | Input shutterAll versions | 1 | PC-ABS | 154 × 25 × 3 mm | | 3D ↗
11 | Dry electronics trayAll versions | 1 | PC-ABS | 196 × 96 × 66 mmwall 3 mm | | 3D ↗
12 | Dry electronics lidAll versions | 1 | PC-ABS | 190 × 90 × 2 mm | | 3D ↗
15 | Display bezelAll versions | 1 | PC-ABS | 101 × 57 × 1 mmwall 7 mm | | 3D ↗
20 | Sealed strip cassetteAll versions | 1 | Polypropylene | 34 × 130 × 45 mmwall 2 mm | Wetted part: polypropylene for service use; PETG is fine for a fit-check print. | 3D ↗
21 | Cassette sealed lidAll versions | 1 | Polypropylene | 30 × 126 × 2 mm | Wetted part: polypropylene for service use; PETG is fine for a fit-check print. | 3D ↗
22 | Optical chamberAll versions | 1 | Black PC-ABS | 158 × 59 × 66 mmwall 2 mm | Light-tight black for the optics. | 3D ↗
23 | Optical removable lidAll versions | 1 | Black PC-ABS | 154 × 55 × 2 mm | Light-tight black for the optics. | 3D ↗
24 | Optical insert baffleAll versions | 1 | Black PC-ABS | 148 × 49 × 7 mmwall 3 mm | Light-tight black for the optics. | 3D ↗
25 | Strip datum carrierAll versions | 1 | Polypropylene | 137 × 13 × 8 mmwall 1 mm | Wetted part: polypropylene for service use; PETG is fine for a fit-check print. | 3D ↗
28 | Optical scan carriageAll versions | 1 | Black PC-ABS | 28 × 28 × 3 mmwall 5 mm | Light-tight black for the optics. | 3D ↗
30 | Left LED bracketAll versions | 1 | Black PC-ABS | 10 × 16 × 3 mmwall 2 mm | Light-tight black for the optics. | 3D ↗
31 | Right LED bracketAll versions | 1 | Black PC-ABS | 10 × 16 × 3 mmwall 2 mm | Light-tight black for the optics. | 3D ↗
37 | Sample drawer moduleAll versions | 1 | Polypropylene | 154 × 24 × 51 mmwall 2 mm | Wetted part: polypropylene for service use; PETG is fine for a fit-check print. | 3D ↗
38 | Wet dry barrierAll versions | 1 | PC-ABS | 198 × 3 × 112 mm | | 3D ↗
39 | Drip trayAll versions | 1 | Polypropylene | 148 × 12 × 72 mmwall 2 mm | Wetted part: polypropylene for service use; PETG is fine for a fit-check print. | 3D ↗
40 | Used strip waste cartridgeAll versions | 1 | Polypropylene | 142 × 56 × 93 mmwall 2 mm | Wetted part: polypropylene for service use; PETG is fine for a fit-check print. | 3D ↗
41 | Waste transport lidAll versions | 1 | Polypropylene | 138 × 52 × 2 mmwall 6 mm | Wetted part: polypropylene for service use; PETG is fine for a fit-check print. | 3D ↗
42 | Waste closure slideAll versions | 1 | Polypropylene | 125 × 38 × 1 mm | Wetted part: polypropylene for service use; PETG is fine for a fit-check print. | 3D ↗
43 | Cleaning fluid cartridgeAll versions | 1 | Polypropylene | 24 × 60 × 48 mmwall 2 mm | Wetted part: polypropylene for service use; PETG is fine for a fit-check print. | 3D ↗
44 | Battery trayBattery version | 1 | PC-ABS | 81 × 29 × 47 mmwall 2 mm | | 3D ↗
46 | DC connector bracketDC version | 1 | PC-ABS | 20 × 16 × 3 mmwall 4 mm | | 3D ↗
50 | Cable channelAll versions | 1 | PC-ABS | 8 × 188 × 7 mmwall 2 mm | | 3D ↗
— | Pedestal headPedestal mount | 1 | PC-ABS | 100 × 90 × 44 mm | | 3D ↗

## Stainless-steel parts

304 stainless steel, laser-cut, bent or machined. Send the STL or STEP files to a sheet-metal service. Plate thickness is the smallest dimension.

# | Part | Qty | Material | Size (W × H × D) | Notes

08 | Universal mount plateAll versions | 1 | 304 stainless steel | 180 × 260 × 4 mm | 4 × Ø5 mm holes, 12 mm from the side edges and 14 mm from the top and bottom edges. | 3D ↗
09 | Rear standoff LAll versions | 1 | 304 stainless steel | 12 × 245 × 4 mm | Ø4.5 mm screw clearances. | 3D ↗
10 | Rear standoff RAll versions | 1 | 304 stainless steel | 12 × 245 × 4 mm | Ø4.5 mm screw clearances. | 3D ↗
27 | Scan railAll versions | 1 | 304 stainless steel | 142 × 6 × 6 mm | 6 × 6 mm guide bar. | 3D ↗
— | Hook adapterHook mount | 1 | 304 stainless steel | 180 × 260 × 4 mm | 4 × Ø5 mm holes, 12 mm from the side edges and 14 mm from the top and bottom edges. | 3D ↗
— | Hook front dropHook mount | 1 | 304 stainless steel | 70 × 75 × 4 mm | | 3D ↗
— | Hook rear dropHook mount | 1 | 304 stainless steel | 70 × 60 × 4 mm | | 3D ↗
— | Hook top bridgeHook mount | 1 | 304 stainless steel | 70 × 4 × 68 mm | | 3D ↗
— | Magnetic adapterMagnetic mount | 1 | 304 stainless steel | 180 × 260 × 4 mm | 4 × Ø5 mm holes, 12 mm from the side edges and 14 mm from the top and bottom edges. | 3D ↗
— | Partition adapterPartition mount | 1 | 304 stainless steel | 180 × 260 × 4 mm | 4 × Ø5 mm holes, 12 mm from the side edges and 14 mm from the top and bottom edges. | 3D ↗
— | Partition bridgePartition mount | 2 | 304 stainless steel | 4 × 35 × 66 mm | | 3D ↗
— | Partition fixed jawPartition mount | 2 | 304 stainless steel | 40 × 35 × 4 mm | | 3D ↗
— | Partition moving jawPartition mount | 2 | 304 stainless steel | 40 × 35 × 4 mm | | 3D ↗
— | Pedestal adapterPedestal mount | 1 | 304 stainless steel | 180 × 260 × 4 mm | 4 × Ø5 mm holes, 12 mm from the side edges and 14 mm from the top and bottom edges. | 3D ↗
— | Pedestal ballast basePedestal mount | 1 | 304 stainless steel | 500 × 30 × 500 mm | About 60 kg steel. Stability limits are documented in ENGINEERING.md. | 3D ↗
— | Pedestal towerPedestal mount | 1 | 304 stainless steel | 60 × 1200 × 6 mm | 60 × 6 mm section; stiffness not verified. | 3D ↗
— | Rail adapterRail mount | 1 | 304 stainless steel | 180 × 260 × 4 mm | 4 × Ø5 mm holes, 12 mm from the side edges and 14 mm from the top and bottom edges. | 3D ↗
— | Rail bridgeRail mount | 2 | 304 stainless steel | 12 × 20 × 5 mm | | 3D ↗
— | Rail front halfRail mount | 2 | 304 stainless steel | 54 × 54 × 20 mmwall 4 mm | Half of a Ø54 × 4 mm stainless tube, 20 mm long. | 3D ↗
— | Rail rear halfRail mount | 2 | 304 stainless steel | 54 × 54 × 20 mmwall 4 mm | Half of a Ø54 × 4 mm stainless tube, 20 mm long. | 3D ↗
— | Smooth adapterSmooth mount | 1 | 304 stainless steel | 180 × 260 × 4 mm | 4 × Ø5 mm holes, 12 mm from the side edges and 14 mm from the top and bottom edges. | 3D ↗

## EPDM rubber parts

Die-cut or knife-cut from EPDM sheet. The rail inserts are half-shells (Ø46 mm outside, Ø32 mm inside, 20 mm long).

# | Part | Qty | Material | Size (W × H × D) | Notes

07 | Door EPDM gasketAll versions | 1 | EPDM | 224 × 324 × 1 mmwall 3 mm | | 3D ↗
49 | Strain reliefAll versions | 1 | EPDM | 18 × 12 × 5 mmwall 3 mm | | 3D ↗
— | Hook protective padHook mount | 1 | EPDM | 66 × 2 × 53 mm | | 3D ↗
— | Partition pad frontPartition mount | 2 | EPDM | 36 × 31 × 2 mm | | 3D ↗
— | Partition pad rearPartition mount | 2 | EPDM | 36 × 31 × 2 mm | | 3D ↗
— | Rail insert front 32mmRail mount | 2 | EPDM | 46 × 46 × 20 mmwall 7 mm | | 3D ↗
— | Rail insert rear 32mmRail mount | 2 | EPDM | 46 × 46 × 20 mmwall 7 mm | | 3D ↗

## Mount kits

You only need one mount. Each kit also includes its own 180 × 260 × 4 mm adapter plate.

- Partition Show in 3D ↗
  - 1 × Partition adapter: 180 × 260 × 4 mm, 304 stainless steel
  - 2 × Partition fixed jaw: 40 × 35 × 4 mm, 304 stainless steel
  - 2 × Partition bridge: 4 × 35 × 66 mm, 304 stainless steel
  - 2 × Partition moving jaw: 40 × 35 × 4 mm, 304 stainless steel
  - 2 × Partition pad front: 36 × 31 × 2 mm, EPDM
  - 2 × Partition pad rear: 36 × 31 × 2 mm, EPDM
  - 2 × Partition M8 screw: 8 × 8 × 16 mm, 304 stainless steel
- Rail Show in 3D ↗
  - 1 × Rail adapter: 180 × 260 × 4 mm, 304 stainless steel
  - 2 × Rail front half: 54 × 54 × 20 mm, 304 stainless steel
  - 2 × Rail rear half: 54 × 54 × 20 mm, 304 stainless steel
  - 2 × Rail insert front 32mm: 46 × 46 × 20 mm, EPDM
  - 2 × Rail insert rear 32mm: 46 × 46 × 20 mm, EPDM
  - 2 × Rail bridge: 12 × 20 × 5 mm, 304 stainless steel
- Hook Show in 3D ↗
  - 1 × Hook adapter: 180 × 260 × 4 mm, 304 stainless steel
  - 1 × Hook top bridge: 70 × 4 × 68 mm, 304 stainless steel
  - 1 × Hook front drop: 70 × 75 × 4 mm, 304 stainless steel
  - 1 × Hook rear drop: 70 × 60 × 4 mm, 304 stainless steel
  - 1 × Hook protective pad: 66 × 2 × 53 mm, EPDM
- Pedestal Show in 3D ↗
  - 1 × Pedestal adapter: 180 × 260 × 4 mm, 304 stainless steel
  - 1 × Pedestal ballast base: 500 × 30 × 500 mm, 304 stainless steel
  - 1 × Pedestal tower: 60 × 1200 × 6 mm, 304 stainless steel
  - 1 × Pedestal head: 100 × 90 × 44 mm, PC-ABS
- Smooth Show in 3D ↗
  - 1 × Smooth adapter: 180 × 260 × 4 mm, 304 stainless steel
  - 4 × Smooth pad: 50 × 55 × 2 mm, COTS removable pad UNRATED
- Magnetic Show in 3D ↗
  - 1 × Magnetic adapter: 180 × 260 × 4 mm, 304 stainless steel
  - 4 × Magnet pot: 32 × 32 × 7 mm, COTS magnet UNRATED

## Tools

- 3D printer (≥ 330 mm build for the shell, or split it)
- Enclosure or heated chamber for PC-ABS
- Laser-cutting and bending service
- Soldering iron and solder
- Multimeter
- Heat-set insert tip
- Drill and Ø5 mm bit
- Hex keys and screwdrivers
- Wire strippers and crimper (JST-XH)
- Computer with the Arduino IDE and a USB-B cable

## Assembly, step by step

Follow the order in the engineering notes: sealed compartments first, then optics, handling, power, front and mount. Each step links to the 3D viewer with its parts highlighted.

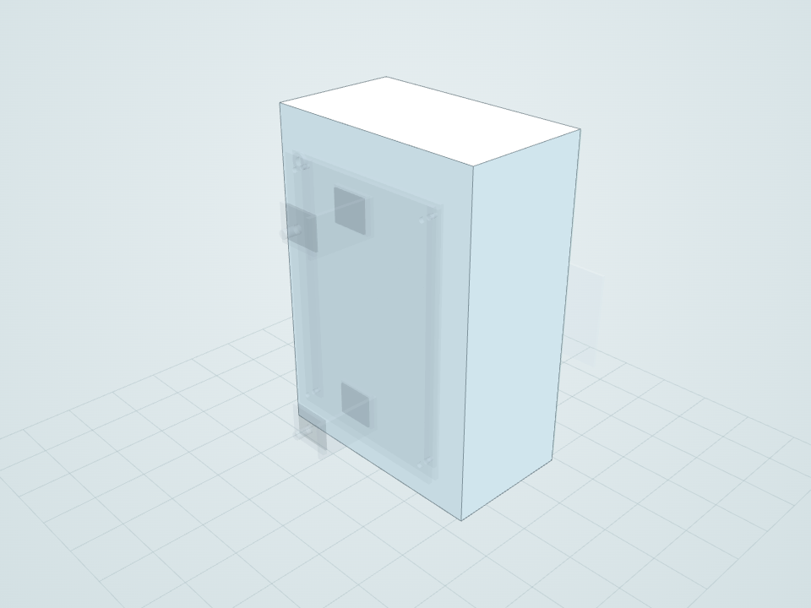
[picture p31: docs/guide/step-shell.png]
Main shell of the Luma reader highlighted, seen from the back


Highlighted: parts fitted in this step. Show in 3D ↗

### 1Prepare the parts

1. Print the enclosure, trays and brackets (see printed parts). The main shell (01, 230 × 330 × 128 mm) is the largest print.
2. Have the stainless-steel parts laser-cut and bent (see steel parts), and die-cut the EPDM gaskets and pads (see rubber parts).
3. Melt four M4 heat-set inserts into the back wall of the shell at x ±78 mm, y 49 mm and y 281 mm. These carry the mounting plate.
4. Program the Arduino and test every electronic module on the bench before it goes into the enclosure.

Check: Dry-fit the trays and cassettes in the shell before gluing or fastening anything.

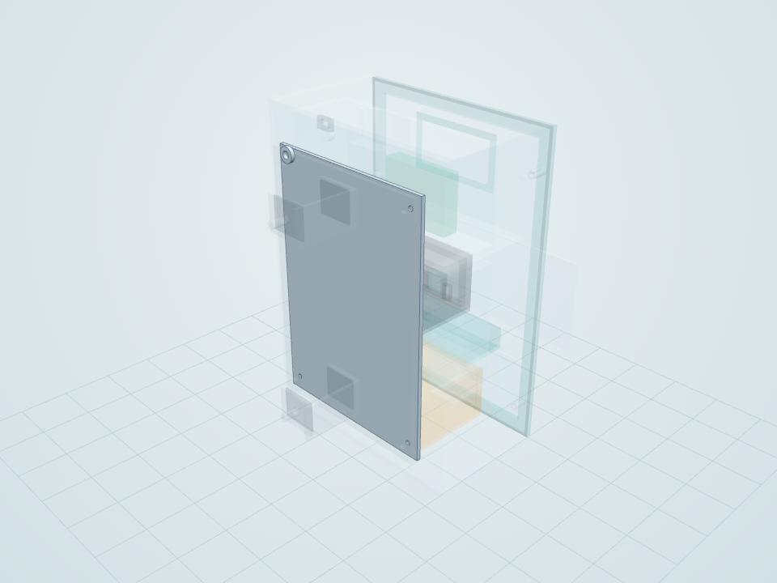
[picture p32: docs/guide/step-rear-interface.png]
Rear mounting plate, standoffs, tether eye and M4 screws highlighted on the back of the reader


Highlighted: parts fitted in this step. Show in 3D ↗

### 2Fit the rear mounting interface

1. Place the two rear standoffs (09, 10) vertically on the back of the shell (x −84…84, y 43…288, z −4…0 mm).
2. Lay the universal mounting plate (08, 180 × 260 × 4 mm stainless) over them.
3. Fix the stack with the four M4 captive screws (59) into the heat-set inserts at x ±78 mm, y 49 and 281 mm.
4. Fit the tether eye (58) at the upper right of the back (x 69…85, y 280…296, z −12…−8 mm).

Check: The plate sits flat and the screws stay captive when undone. Every mount adapter uses the same four holes.

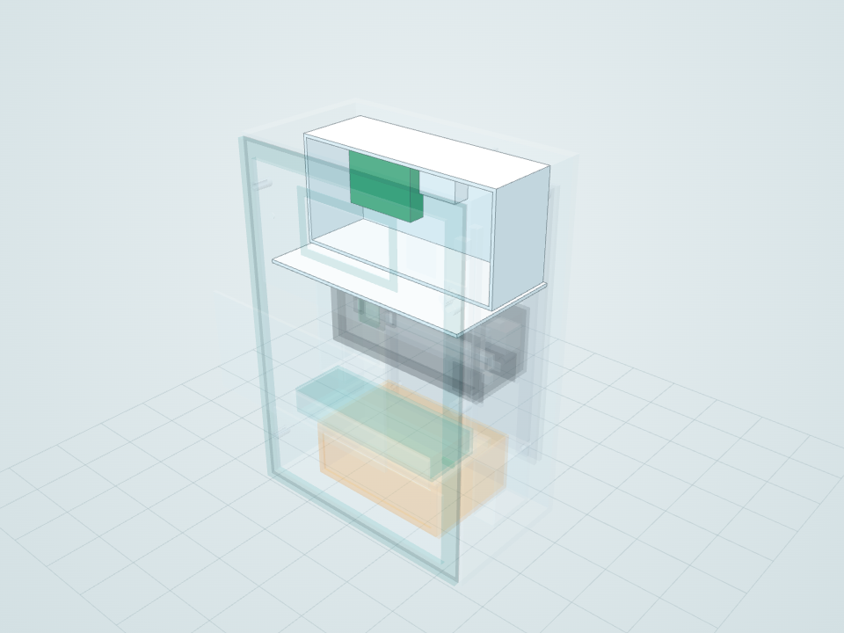
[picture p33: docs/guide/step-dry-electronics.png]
Dry electronics compartment highlighted: wet/dry barrier, tray, Arduino, fuse module and buzzer


Highlighted: parts fitted in this step. Show in 3D ↗

### 3Build the dry electronics compartment

1. Fit the wet/dry barrier (38), a full-width horizontal shelf at y 219–222 mm. Everything above it stays dry.
2. Seal the barrier and fit the dry electronics tray (11) above it against the back wall (x −98…98, y 224…320, z 12…78 mm). Leak-check this compartment before installing electronics.
3. Arduino Uno (13): mount it upright on four 5 mm M3 standoffs on the tray’s back wall, in the upper-left corner (x −89…−20, y 250…304, z 20…36 mm), headers facing the front.
4. Fit the fuse module (14) to the right of the Arduino (x −10…27, y 278…305, z 20…36 mm), the buzzer (19) at the top right (x 65…79, y 292…306, z 30…37 mm) and the strain relief (49) where cables leave at the top (x 58…76, y 305…317, z 25…30 mm).
5. Mount the stepper driver and any small boards that aren’t modelled in the free area right of the fuse module (about x 30…95, y 225…290 mm). Then wire everything (see wiring) and close the lid (12).

Check: The USB port is still reachable, no wire is pinched by the lid, and the compartment passed its leak check.

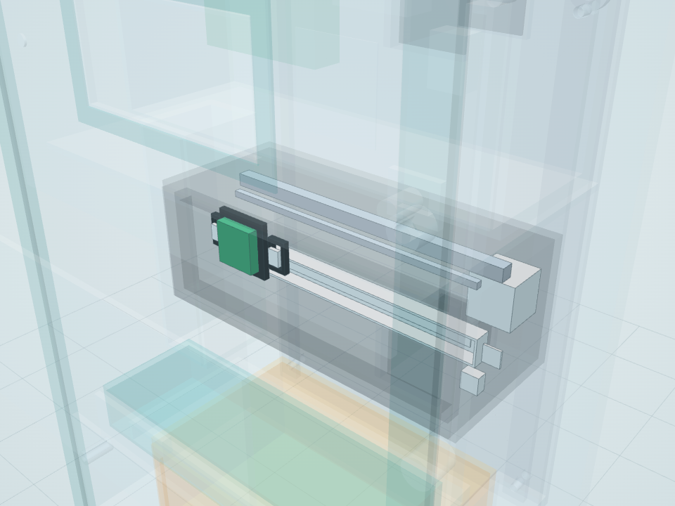
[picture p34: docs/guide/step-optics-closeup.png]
Close-up of the optical scan carriage with RGB sensor, two LEDs, strip carrier, rail, lead screw and motor


Highlighted: parts fitted in this step. Show in 3D ↗

### 4Assemble the optical module

1. Fit the black optical chamber (22, x −64…94, y 145…204, z 22…88 mm) and its light baffle insert (24).
2. Fix the strip datum carrier (25). It holds the test strip (26) flat at z 52 mm.
3. Mount the scan rail (27) and M3 lead screw (36) along the top of the chamber, and the micro stepper (35) at the right end.
4. Build the scan carriage (28): the TCS34725 sensor (29) in the centre facing the strip, and the two white LEDs (32, 33) on brackets 30 and 31, 38 mm apart, angled at the strip.
5. Place the white reference tile (34) at the right end of the travel, level with the strip, and the home / jam sensor (54) beside it.
6. Close the chamber with its removable lid (23).

The CAD puts the sensor face 14.5 mm above the pads; the engineering notes suggest testing 5–25 mm on a jig.

Check: With the lid closed, the sensor reads close to zero with the LEDs off (dark reading). The carriage reaches the reference tile at the end of its travel.

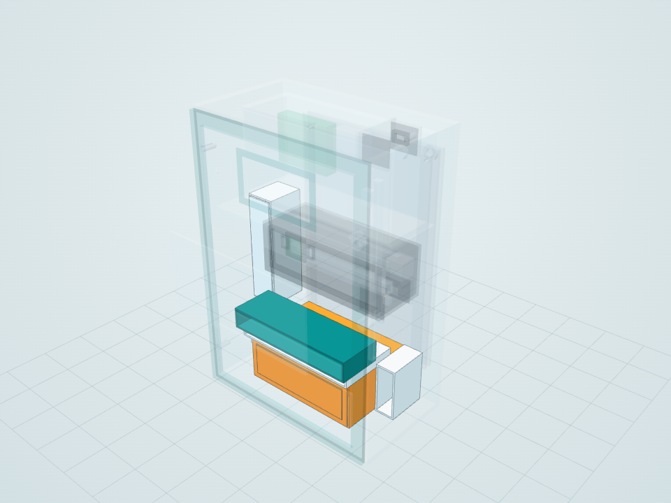
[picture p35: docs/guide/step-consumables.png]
Clean strip cassette, sample drawer, drip tray, waste cartridge and cleaning cartridge highlighted


Highlighted: parts fitted in this step. Show in 3D ↗

### 5Install strip handling and consumables

1. Slide the sealed clean-strip cassette (20) and its lid (21) into the left column (x −106…−72, y 87…217, z 22…67 mm).
2. Fit the sample drawer (37) behind the input shutter, with the drip tray (39) underneath it.
3. Insert the used-strip waste cartridge (40) at the bottom (x −66…76, y 16…72, z 17…110 mm), with its transport lid (41) and closure slide (42).
4. Fit the cleaning-fluid cartridge (43) at the bottom right (x 81…105, y 20…80, z 25…73 mm).
5. Mount the cartridge-present sensor (52) beside the waste cartridge and the drip-overflow sensor (53) at the drip tray.

Check: Each cassette, tray and cartridge comes out from the front without exposing the clean strips. Prove the motion and jam recovery without samples before any fluid testing.

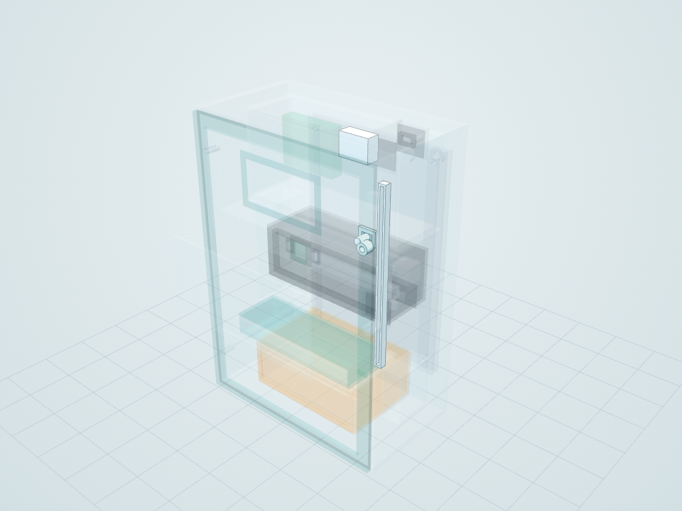
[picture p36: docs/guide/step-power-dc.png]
DC jack, cable gland, cable channel and fuse module highlighted


Highlighted: parts fitted in this step. Show in 3D ↗

### 6Connect the power

DC version: mount the DC jack (47) on its bracket (46) at the upper right (x 66…86, y 230…246, z 93…109 mm), with the cable gland (48) beside it. Run the supply through the reverse-polarity diode and fuse module (14) to the Arduino and motor driver.

Battery version: fit the battery tray (44) in front of the dry-compartment lid (x −91…−10, y 228…257, z 82…129 mm) and place the protected 2S pack (45) in it. Show the battery version ↗

Route the harness down the cable channel (50) on the right side (x 99…107, y 114…302, z 103…110 mm), clipped above any area that can hold liquid.

Check: Polarity, fuse values and the 5 V rail are checked with a multimeter before the Arduino is connected.

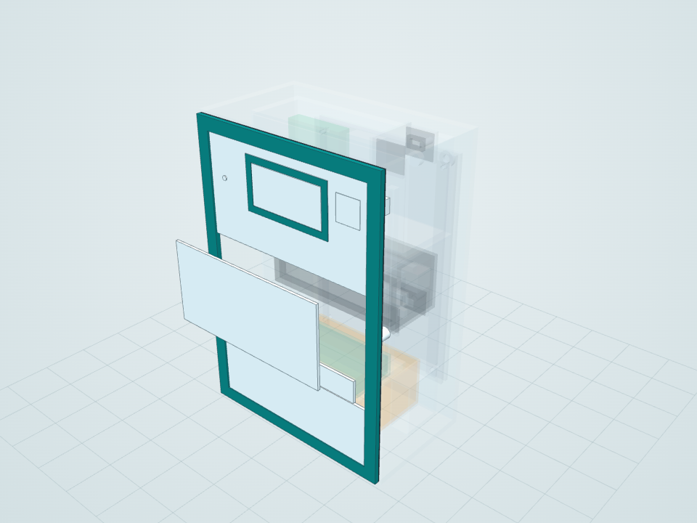
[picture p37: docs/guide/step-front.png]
Front panels, door frame, gasket, hinges, display window, interlock and lock highlighted


Highlighted: parts fitted in this step. Show in 3D ↗

### 7Fit the front panels and door

1. Fit the EPDM gasket (07) to the door frame (02), and hang the frame on the two hinges (55, 56) on the left edge.
2. Mount the display module behind the 84 × 40 mm opening in the upper front panel (03), then fit the polycarbonate window (16), bezel (15), status LED (18) and QR label (17).
3. Fit the optics front cover (05), the lower front panel (04) and the input shutter (06).
4. Fit the door interlock switch (51) at the upper right (x 99…109, y 284…298, z 118…125 mm) and the service lock (57) on the right edge (x 98…110, y 158…170, z 114…127 mm).

Check: The door closes evenly on the gasket, the interlock switches when it opens, and the lock holds it shut.

### 8Choose and attach a mount

Pick the mount that suits the site. Every adapter is a 180 × 260 × 4 mm stainless plate that bolts to the universal plate through the same four holes. Then fit the mount-specific parts (see mount kits):

Rear view of the partition mount

Partition: Padded jaws, 12–50 mm panels

Rear view of the rail mount

Rail: Split clamp, 32 mm post

Rear view of the hook mount

Hook: Over-partition hook

Rear view of the pedestal mount

Pedestal: Ballasted floor stand

Rear view of the smooth mount

Smooth: Removable pads + tether

Rear view of the magnetic mount

Magnetic: Pot magnets + tether

Check: Do a site survey before choosing a mount, and proof-test the installation off-site before public use (see ENGINEERING.md).

## Wiring

A suggested pin map for the Arduino Uno. The CAD does not define wiring and no firmware is included yet, so treat this as a starting point.

Arduino pin | Connects to | # | Notes
A4 (SDA), A5 (SCL) | TCS34725 sensor and LCD backpack | 29 | Shared I²C bus: sensor 0x29, LCD 0x27 or 0x3F
5V, GND | Sensor, LCD, switches and sensor boards | — | Logic power only; the motor has its own fused supply
D3 / D4 | Stepper driver STEP / DIR | 35 | DRV8834; set the current limit first
D7 | Stepper driver SLEEP (enable) | 35 | Pull low whenever the door is open
D5 / D6 | Left / right white LED, each through 150 Ω | 32 33 | PWM pins, so brightness can be trimmed
D8 | TCS34725 LED pin | 29 | Held LOW to keep the board’s own LED off
D2 | TCS34725 INT (optional) | 29 | Interrupt when a reading is ready
D9 | Piezo buzzer | 19 | tone()
D10 | Status LED through 330 Ω | 18
D11 | Door interlock switch to GND | 51 | INPUT_PULLUP
D12 | Cartridge-present sensor to GND | 52 | INPUT_PULLUP
A0 | Drip-overflow probe | 53 | Analog reading
A1 | Home / jam sensor output | 54 | Use a breakout that includes its resistors
A2 | Battery voltage through a 10 kΩ / 10 kΩ divider | 45 | Battery version: 8.4 V full reads as 4.2 V
VIN | Supply after the diode and fuse F1 | 14 | 7–12 V
D0, D1, D13 | Leave free | — | USB serial and the on-board LED

### Power path

DC jack (47) or battery pack (45) → Schottky diode → fuse module (14): F1 feeds the Arduino’s VIN and F2 feeds the stepper driver’s motor supply. The Arduino’s 5 V rail powers the sensor, LCD, LEDs and switches. A 2S pack falls below the Uno’s recommended 7 V near the end of its charge: stop at about 7 V (read on A2), or add a 5 V regulator.

## First power-up and testing

1. Before power: check continuity, polarity and fuse values with a multimeter.
2. Power up with the motor unplugged and check the 5 V rail.
3. Run an I²C scanner sketch: the sensor should appear at 0x29 and the LCD at 0x27 or 0x3F.
4. Close the optics lid and take a dark reading with the LEDs off; it should be close to zero.
5. Read the white reference tile (34) repeatedly and check the readings are repeatable.
6. Connect the motor and set the driver’s current limit. Check homing, full travel and jam recovery without samples.
7. Check the interlocks: opening the door stops motion, a missing or full cartridge blocks testing, and an overflow stops sample intake.
8. Only then move on to wet tests, and calibrate for each pad and strip supplier.

## Servicing

1. Disable motion.
2. Close the waste cartridge slide (42), then withdraw and replace the waste cartridge (40). Never empty it through the clean compartment.
3. Remove and wash or replace the wetted insert, and inspect the seals.
4. Refill the clean strips through the clean access path (20).
5. Replace the protected battery if fitted.
6. Close and lock the covers, then run the reference and sensor checks.

## Budget

Planning allowances from the engineering notes (INR). These are not supplier quotes.

Category | Allowance (INR)
Sensor, Uno, LEDs and wiring | 1,167
100-strip pack | 1,500
Printed enclosure and removable trays | 2,000–4,500
One mechanical mount, locks, seals, fasteners | 1,500–3,500
Display and interface | 500–1,500
Motion, bearings, driver, interlocks | 1,000–3,000
Power and protection | 700–2,000
Optical finish, calibration, cleaning provisions | 500–1,500
Total (before stand, connectivity, labour and validation) | 8,867–18,667

Before installing anything in a public toilet, complete the site survey and off-site proof test in ENGINEERING.md (https://github.com/tamnisan/luma/blob/main/ENGINEERING.md). Found a problem or built one? Open an issue (https://github.com/tamnisan/luma/issues).

© 2026 tamnisan · Released under the MIT License (https://github.com/tamnisan/luma/blob/main/LICENSE) Home · 3D model · Source on GitHub (https://github.com/tamnisan/luma)

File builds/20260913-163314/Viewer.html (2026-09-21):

Luma Retrofit · 3D modelEngineering prototype · Rev A

Configuration

Design review

Loading model…

IsoFrontRightTopBackFit

X-rayEdgesScreenshot

Parts

Left-drag rotate · Right-drag pan · Scroll zoom · Click a part for details · Double-click to zoom to it

Show all

Engineering prototype, not a fabrication release. See ENGINEERING.md for assumptions and open work.

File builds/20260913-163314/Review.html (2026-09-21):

ENGINEERING PROTOTYPE • REV A

# Luma / Retrofit reader

A compact, removable urine-strip reader with a common enclosure and interchangeable mounts for existing facilities. Native SolidWorks CAD with a transparent record of assumptions and outstanding development.

230 × 330 × 150mm installed interface envelope

105 partsIndividual parametric CAD files

6 × 2 configurationsMount and power combinations

Prototype layout, not a fabrication or deployment release. Automatic strip transfer/ejection, mount load capacity and clinical performance are not validated. See engineering notes and CAD checks.

## Open the design

Interactive 3D model (runs in this browser; no CAD software needed) · STEP files for any CAD program · STL meshes

SolidWorks assembly · Exploded assembly · General arrangement drawing · Bill of materials · Validation record · Engineering notes and installation matrix

The assembly and its parts folder must travel together. Native views are from SolidWorks; the dimensioned elevations below are BOM-derived reference diagrams.

## Dimensions and internal packaging

## Native CAD views

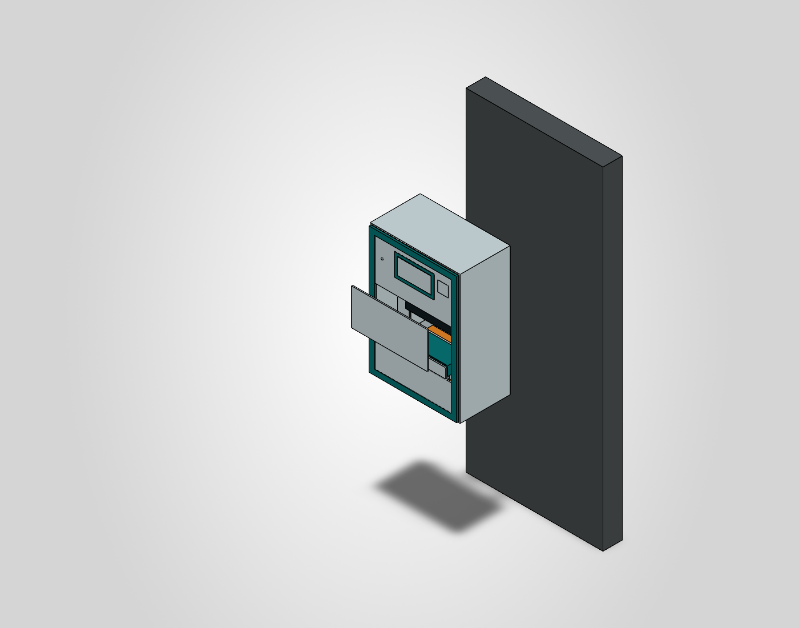
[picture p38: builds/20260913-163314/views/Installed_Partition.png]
Native SolidWorks Installed_Partition view


Installed_Partition / native SolidWorks view. Mount concept; geometry and mechanism limitations apply.

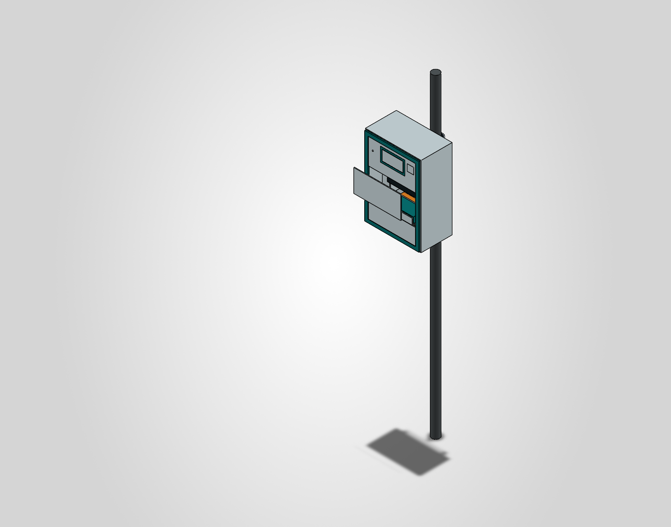
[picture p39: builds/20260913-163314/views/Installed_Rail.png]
Native SolidWorks Installed_Rail view


Installed_Rail / native SolidWorks view. Mount concept; geometry and mechanism limitations apply.

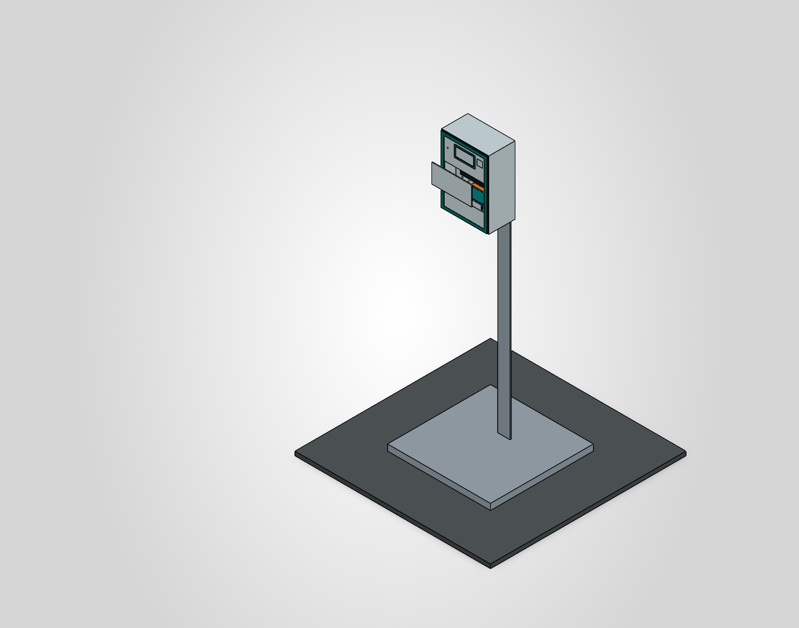
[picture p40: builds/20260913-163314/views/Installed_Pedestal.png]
Native SolidWorks Installed_Pedestal view


Installed_Pedestal / native SolidWorks view. Mount concept; geometry and mechanism limitations apply.

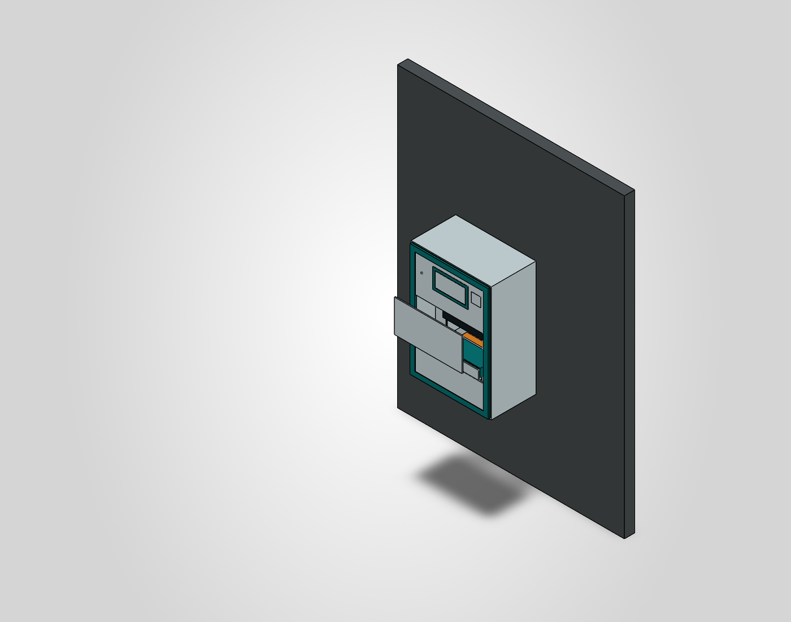
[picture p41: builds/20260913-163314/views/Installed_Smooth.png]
Native SolidWorks Installed_Smooth view


Installed_Smooth / native SolidWorks view. Mount concept; geometry and mechanism limitations apply.

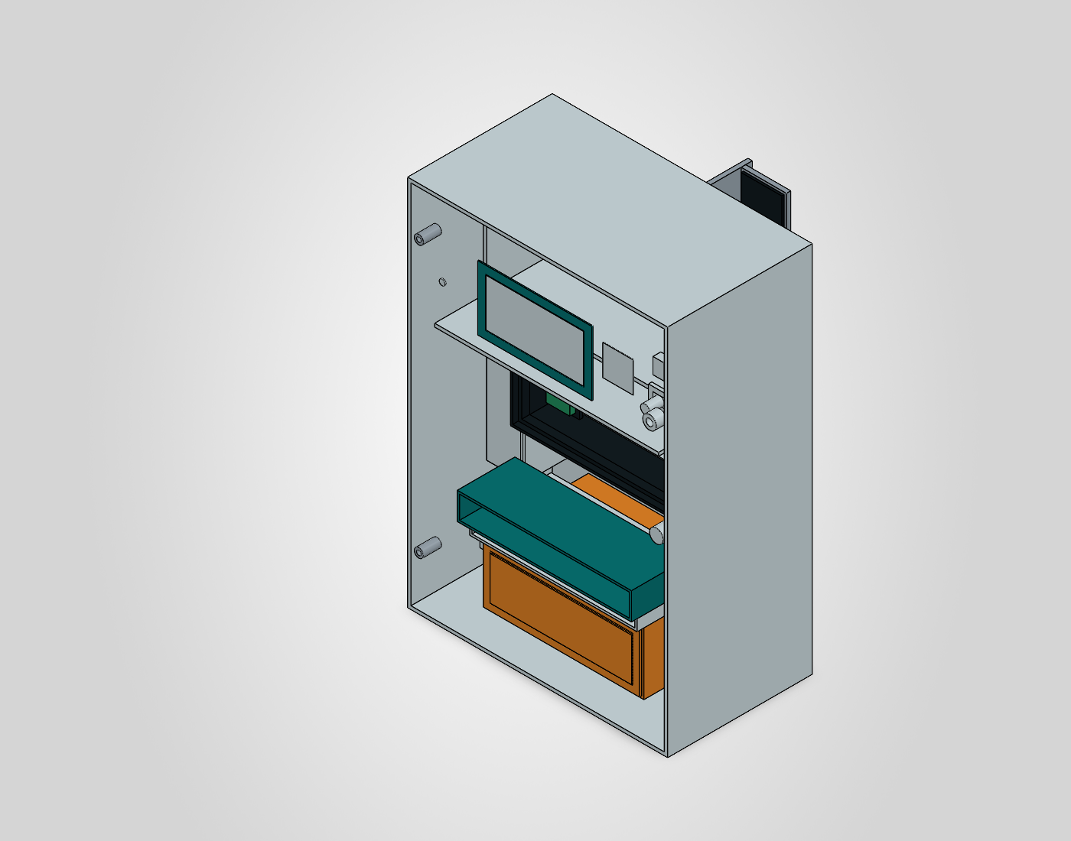
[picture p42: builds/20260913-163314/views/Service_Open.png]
Native SolidWorks Service_Open view


Service_Open / native SolidWorks view. Mount concept; geometry and mechanism limitations apply.

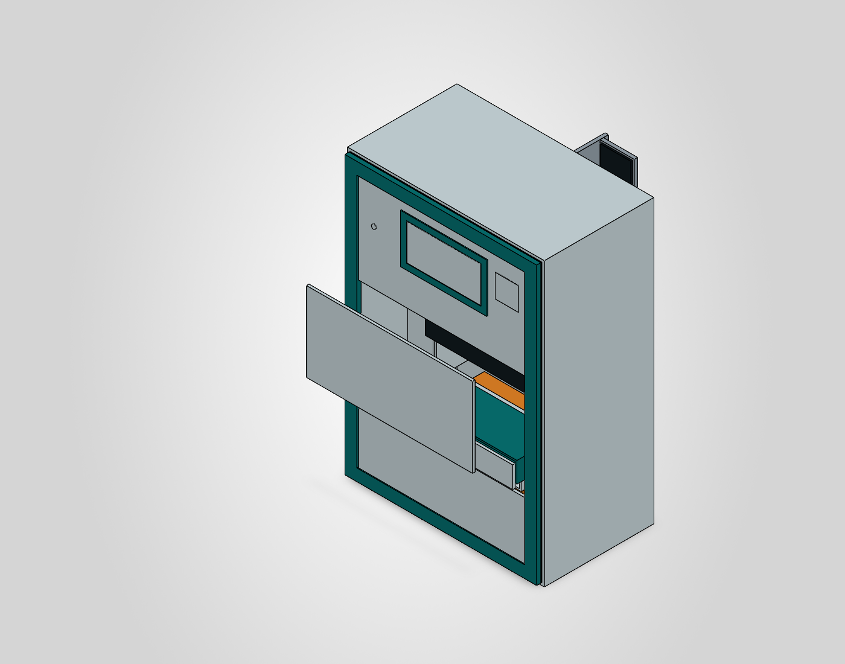
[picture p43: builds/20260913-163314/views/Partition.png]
Native SolidWorks Partition view


Partition / native SolidWorks view. Mount concept; geometry and mechanism limitations apply.

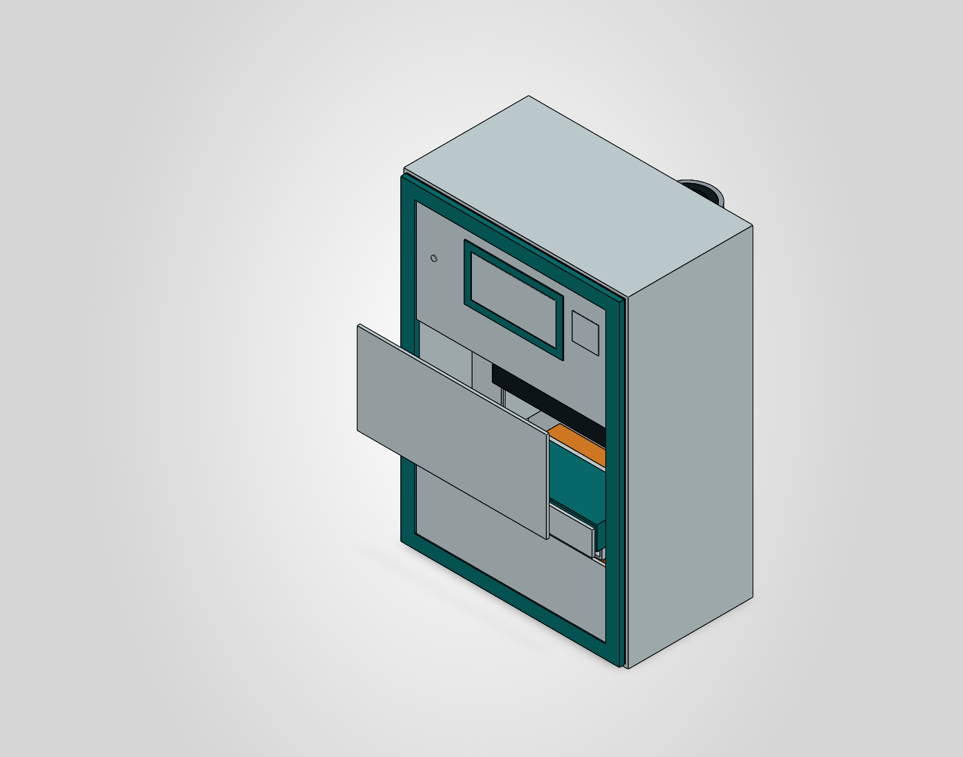
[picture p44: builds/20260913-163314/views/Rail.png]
Native SolidWorks Rail view


Rail / native SolidWorks view. Mount concept; geometry and mechanism limitations apply.

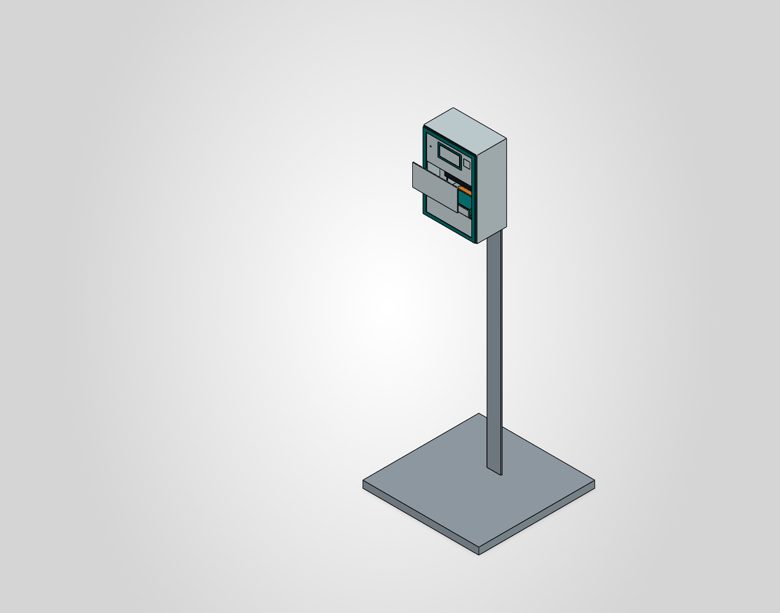
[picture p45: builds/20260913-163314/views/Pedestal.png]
Native SolidWorks Pedestal view


Pedestal / native SolidWorks view. Mount concept; geometry and mechanism limitations apply.

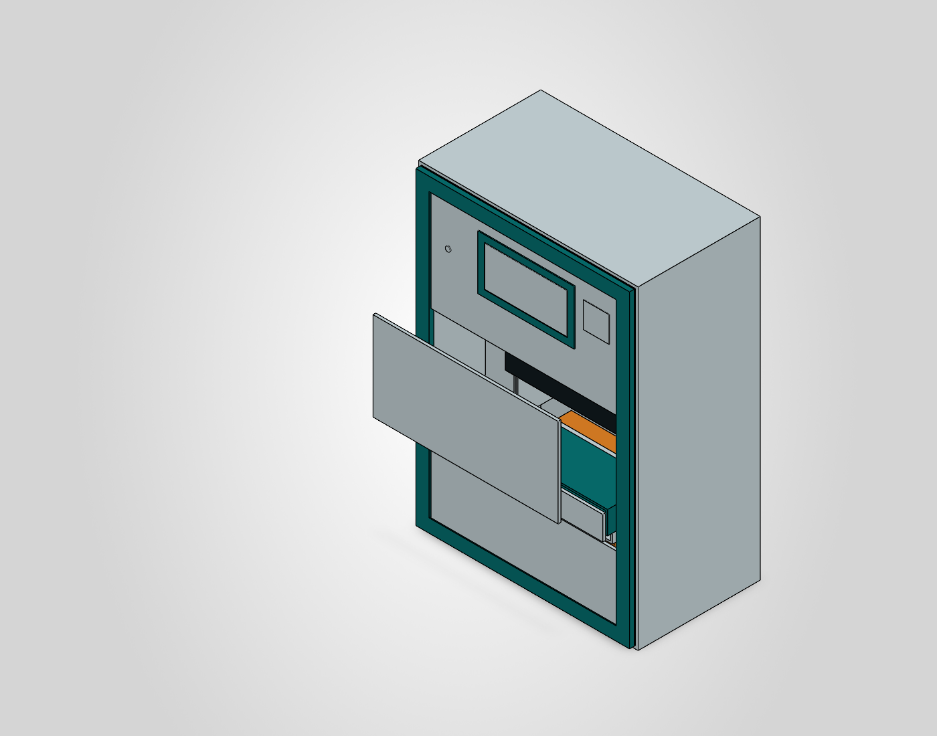
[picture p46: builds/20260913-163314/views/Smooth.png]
Native SolidWorks Smooth view


Smooth / native SolidWorks view. Mount concept; geometry and mechanism limitations apply.

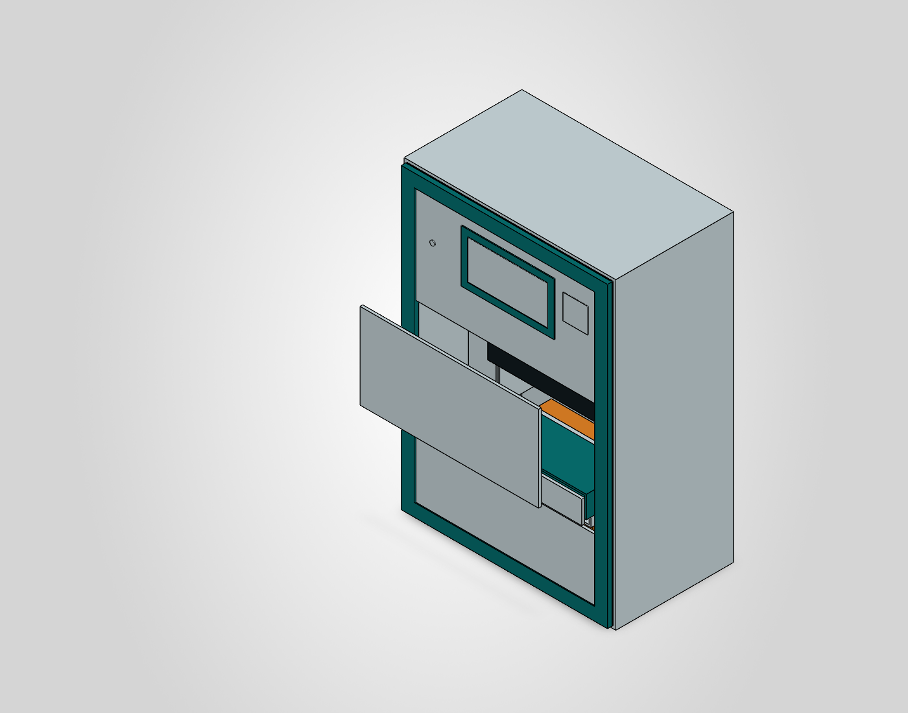
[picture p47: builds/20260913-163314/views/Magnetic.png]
Native SolidWorks Magnetic view


Magnetic / native SolidWorks view. Mount concept; geometry and mechanism limitations apply.

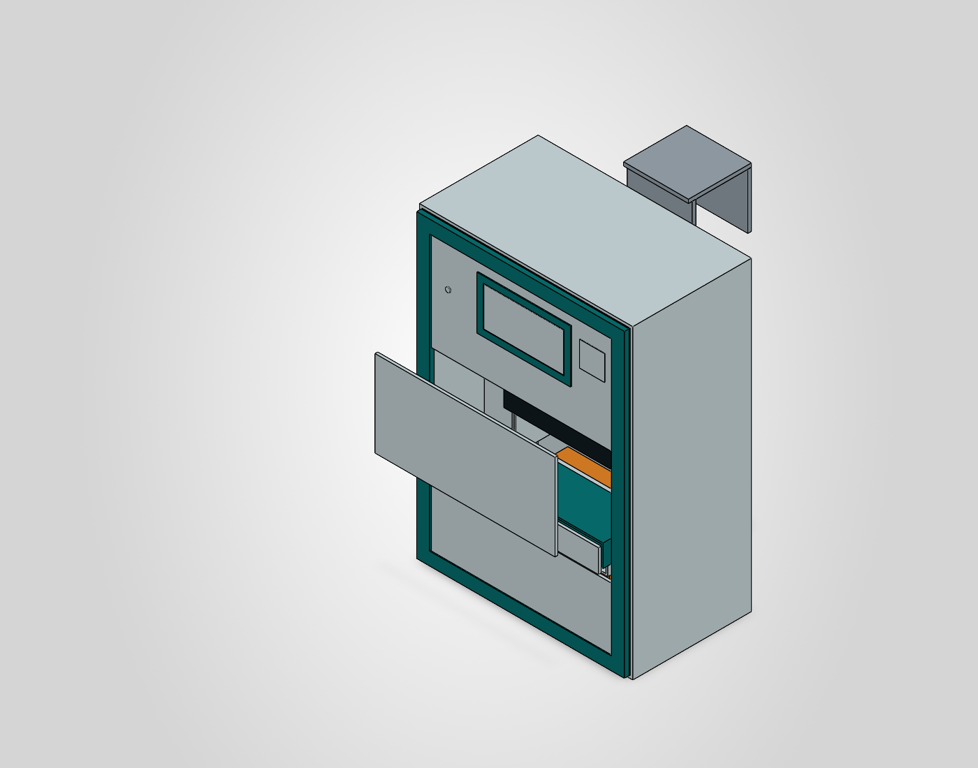
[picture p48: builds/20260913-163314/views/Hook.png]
Native SolidWorks Hook view


Hook / native SolidWorks view. Mount concept; geometry and mechanism limitations apply.

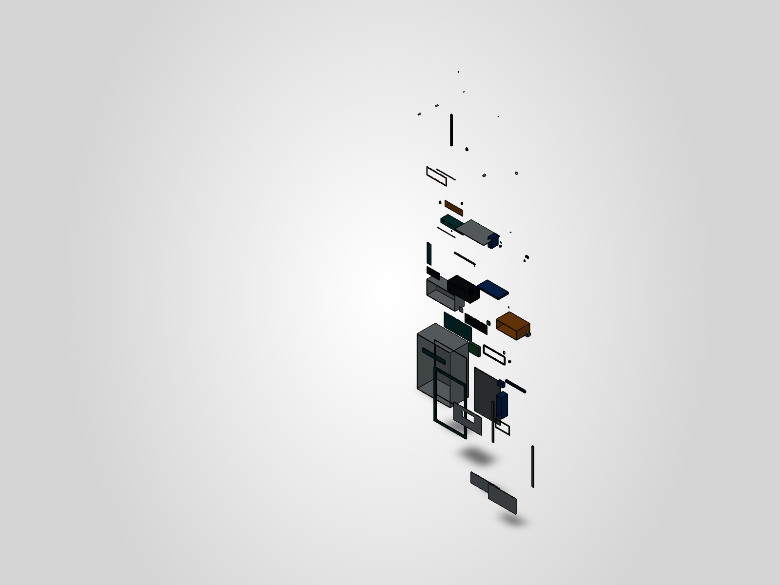
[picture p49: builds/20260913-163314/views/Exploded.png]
Native SolidWorks Exploded view


Exploded / native SolidWorks view. Mount concept; geometry and mechanism limitations apply.

## Preliminary engineering checks

Partition/DC approximate dry mass: 5.39 kg; estimated COG x/y/z: -0.5 / 170.1 / 15.7 mm. Volume-based estimates use assumed material densities and bounding centres, not verified purchased-part masses.

Pedestal assembly mass estimate: 68.95 kg. The 60 kg ballast alone provides 147 N·m restoring moment; a 100 N pull at 1.3 m produces 130 N·m. This small margin is not a safe deployment rating.

Logged sketches not reporting fully constrained: 0. Review the raw log below and the final verification files.

CAD check log

FINAL INSTALLED POSITIONS
Partition_DC INTERFERENCE_COUNT=0
Partition_Battery INTERFERENCE_COUNT=0
Rail_DC INTERFERENCE_COUNT=0
Rail_Battery INTERFERENCE_COUNT=0
Hook_DC INTERFERENCE_COUNT=0
Hook_Battery INTERFERENCE_COUNT=0
Pedestal_DC INTERFERENCE_COUNT=0
Pedestal_Battery INTERFERENCE_COUNT=0
Smooth_DC INTERFERENCE_COUNT=0
Smooth_Battery INTERFERENCE_COUNT=0
Magnetic_DC INTERFERENCE_COUNT=0
Magnetic_Battery INTERFERENCE_COUNT=0

01_Main_shell.SLDPRT reopen=True rebuild=True saved=True errors=0 solids=1
02_Service_door_frame.SLDPRT reopen=True rebuild=True saved=True errors=0 solids=1
03_Upper_front_panel.SLDPRT reopen=True rebuild=True saved=True errors=0 solids=1
04_Lower_front_panel.SLDPRT reopen=True rebuild=True saved=True errors=0 solids=1
05_Optics_front_cover.SLDPRT reopen=True rebuild=True saved=True errors=0 solids=1
06_Input_shutter.SLDPRT reopen=True rebuild=True saved=True errors=0 solids=1
07_Door_EPDM_gasket.SLDPRT reopen=True rebuild=True saved=True errors=0 solids=1
08_Universal_mount_plate.SLDPRT reopen=True rebuild=True saved=True errors=0 solids=1
09_Rear_standoff_L.SLDPRT reopen=True rebuild=True saved=True errors=0 solids=1
10_Rear_standoff_R.SLDPRT reopen=True rebuild=True saved=True errors=0 solids=1
11_Dry_electronics_tray.SLDPRT reopen=True rebuild=True saved=True errors=0 solids=1
12_Dry_electronics_lid.SLDPRT reopen=True rebuild=True saved=True errors=0 solids=1
13_Controller_UNO_envelope.SLDPRT reopen=True rebuild=True saved=True errors=0 solids=1
14_Dual_power_fuse_module.SLDPRT reopen=True rebuild=True saved=True errors=0 solids=1
15_Display_bezel.SLDPRT reopen=True rebuild=True saved=True errors=0 solids=1
16_Display_protective_window.SLDPRT reopen=True rebuild=True saved=True errors=0 solids=1
17_QR_label_area.SLDPRT reopen=True rebuild=True saved=True errors=0 solids=1
18_Status_LED.SLDPRT reopen=True rebuild=True saved=True errors=0 solids=1
19_Buzzer_envelope.SLDPRT reopen=True rebuild=True saved=True errors=0 solids=1
20_Sealed_strip_cassette.SLDPRT reopen=True rebuild=True saved=True errors=0 solids=1
21_Cassette_sealed_lid.SLDPRT reopen=True rebuild=True saved=True errors=0 solids=1
22_Optical_chamber.SLDPRT reopen=True rebuild=True saved=True errors=0 solids=1
23_Optical_removable_lid.SLDPRT reopen=True rebuild=True saved=True errors=0 solids=1
24_Optical_insert_baffle.SLDPRT reopen=True rebuild=True saved=True errors=0 solids=1
25_Strip_datum_carrier.SLDPRT reopen=True rebuild=True saved=True errors=0 solids=1
26_Reagent_strip_envelope.SLDPRT reopen=True rebuild=True saved=True errors=0 solids=1
27_Scan_rail.SLDPRT reopen=True rebuild=True saved=True errors=0 solids=1
28_Optical_scan_carriage.SLDPRT reopen=True rebuild=True saved=True errors=0 solids=1
29_RGB_sensor_envelope.SLDPRT reopen=True rebuild=True saved=True errors=0 solids=1
30_Left_LED_bracket.SLDPRT reopen=True rebuild=True saved=True errors=0 solids=1
31_Right_LED_bracket.SLDPRT reopen=True rebuild=True saved=True errors=0 solids=1
32_Left_LED_envelope.SLDPRT reopen=True rebuild=True saved=True errors=0 solids=1
33_Right_LED_envelope.SLDPRT reopen=True rebuild=True saved=True errors=0 solids=1
34_Calibration_tile.SLDPRT reopen=True rebuild=True saved=True errors=0 solids=1
35_Scan_motor_envelope.SLDPRT reopen=True rebuild=True saved=True errors=0 solids=1
36_Lead_screw_envelope.SLDPRT reopen=True rebuild=True saved=True errors=0 solids=1
37_Sample_drawer_module.SLDPRT reopen=True rebuild=True saved=True errors=0 solids=1
38_Wet_dry_barrier.SLDPRT reopen=True rebuild=True saved=True errors=0 solids=1
39_Drip_tray.SLDPRT reopen=True rebuild=True saved=True errors=0 solids=1
40_Used_strip_waste_cartridge.SLDPRT reopen=True rebuild=True saved=True errors=0 solids=1
41_Waste_transport_lid.SLDPRT reopen=True rebuild=True saved=True errors=0 solids=1
42_Waste_closure_slide.SLDPRT reopen=True rebuild=True saved=True errors=0 solids=1
43_Cleaning_fluid_cartridge.SLDPRT reopen=True rebuild=True saved=True errors=0 solids=1
44_Battery_tray.SLDPRT reopen=True rebuild=True saved=True errors=0 solids=1
45_Battery_protected_pack_envelope.SLDPRT reopen=True rebuild=True saved=True errors=0 solids=1
46_DC_connector_bracket.SLDPRT reopen=True rebuild=True saved=True errors=0 solids=1
47_DC_connector_envelope.SLDPRT reopen=True rebuild=True saved=True errors=0 solids=1
48_Cable_gland.SLDPRT reopen=True rebuild=True saved=True errors=0 solids=1
49_Strain_relief.SLDPRT reopen=True rebuild=True saved=True errors=0 solids=1
50_Cable_channel.SLDPRT reopen=True rebuild=True saved=True errors=0 solids=1
51_Door_interlock.SLDPRT reopen=True rebuild=True saved=True errors=0 solids=1
52_Cartridge_present_switch.SLDPRT reopen=True rebuild=True saved=True errors=0 solids=1
53_Drip_overflow_sensor.SLDPRT reopen=True rebuild=True saved=True errors=0 solids=1
54_Strip_jam_home_sensor.SLDPRT reopen=True rebuild=True saved=True errors=0 solids=1
55_Hinge_lower.SLDPRT reopen=True rebuild=True saved=True errors=0 solids=1
56_Hinge_upper.SLDPRT reopen=True rebuild=True saved=True errors=0 solids=1
57_Service_lock.SLDPRT reopen=True rebuild=True saved=True errors=0 solids=1
58_Tether_eye.SLDPRT reopen=True rebuild=True saved=True errors=0 solids=1
59_M4_captive_fastener_0.SLDPRT reopen=True rebuild=True saved=True errors=0 solids=1
59_M4_captive_fastener_1.SLDPRT reopen=True rebuild=True saved=True errors=0 solids=1
59_M4_captive_fastener_2.SLDPRT reopen=True rebuild=True saved=True errors=0 solids=1
59_M4_captive_fastener_3.SLDPRT reopen=True rebuild=True saved=True errors=0 solids=1
Hook_adapter.SLDPRT reopen=True rebuild=True saved=True errors=0 solids=1
Hook_front_drop.SLDPRT reopen=True rebuild=True saved=True errors=0 solids=1
Hook_protective_pad.SLDPRT reopen=True rebuild=True saved=True errors=0 solids=1
Hook_rear_drop.SLDPRT reopen=True rebuild=True saved=True errors=0 solids=1
Hook_top_bridge.SLDPRT reopen=True rebuild=True saved=True errors=0 solids=1
Magnetic_adapter.SLDPRT reopen=True rebuild=True saved=True errors=0 solids=1
Magnet_pot_0.SLDPRT reopen=True rebuild=True saved=True errors=0 solids=1
Magnet_pot_1.SLDPRT reopen=True rebuild=True saved=True errors=0 solids=1
Magnet_pot_2.SLDPRT reopen=True rebuild=True saved=True errors=0 solids=1
Magnet_pot_3.SLDPRT reopen=True rebuild=True saved=True errors=0 solids=1
Partition_adapter.SLDPRT reopen=True rebuild=True saved=True errors=0 solids=1
Partition_bridge_0.SLDPRT reopen=True rebuild=True saved=True errors=0 solids=1
Partition_bridge_1.SLDPRT reopen=True rebuild=True saved=True errors=0 solids=1
Partition_fixed_jaw_0.SLDPRT reopen=True rebuild=True saved=True errors=0 solids=1
Partition_fixed_jaw_1.SLDPRT reopen=True rebuild=True saved=True errors=0 solids=1
Partition_M8_screw_0.SLDPRT reopen=True rebuild=True saved=True errors=0 solids=1
Partition_M8_screw_1.SLDPRT reopen=True rebuild=True saved=True errors=0 solids=1
Partition_moving_jaw_0.SLDPRT reopen=True rebuild=True saved=True errors=0 solids=1
Partition_moving_jaw_1.SLDPRT reopen=True rebuild=True saved=True errors=0 solids=1
Partition_pad_front_0.SLDPRT reopen=True rebuild=True saved=True errors=0 solids=1
Partition_pad_front_1.SLDPRT reopen=True rebuild=True saved=True errors=0 solids=1
Partition_pad_rear_0.SLDPRT reopen=True rebuild=True saved=True errors=0 solids=1
Partition_pad_rear_1.SLDPRT reopen=True rebuild=True saved=True errors=0 solids=1
Pedestal_adapter.SLDPRT reopen=True rebuild=True saved=True errors=0 solids=1
Pedestal_ballast_base.SLDPRT reopen=True rebuild=True saved=True errors=0 solids=1
Pedestal_head.SLDPRT reopen=True rebuild=True saved=True errors=0 solids=1
Pedestal_tower.SLDPRT reopen=True rebuild=True saved=True errors=0 solids=1
Rail_adapter.SLDPRT reopen=True rebuild=True saved=True errors=0 solids=1
Rail_bridge_0.SLDPRT reopen=True rebuild=True saved=True errors=0 solids=1
Rail_bridge_1.SLDPRT reopen=True rebuild=True saved=True errors=0 solids=1
Rail_front_half_0.SLDPRT reopen=True rebuild=True saved=True errors=0 solids=1
Rail_front_half_1.SLDPRT reopen=True rebuild=True saved=True errors=0 solids=1
Rail_insert_front_32mm_0.SLDPRT reopen=True rebuild=True saved=True errors=0 solids=1
Rail_insert_front_32mm_1.SLDPRT reopen=True rebuild=True saved=True errors=0 solids=1
Rail_insert_rear_32mm_0.SLDPRT reopen=True rebuild=True saved=True errors=0 solids=1
Rail_insert_rear_32mm_1.SLDPRT reopen=True rebuild=True saved=True errors=0 solids=1
Rail_rear_half_0.SLDPRT reopen=True rebuild=True saved=True errors=0 solids=1
Rail_rear_half_1.SLDPRT reopen=True rebuild=True saved=True errors=0 solids=1
REFERENCE_Partition.SLDPRT reopen=True rebuild=True saved=True errors=0 solids=1
REFERENCE_Pedestal.SLDPRT reopen=True rebuild=True saved=True errors=0 solids=1
REFERENCE_Rail.SLDPRT reopen=True rebuild=True saved=True errors=0 solids=1
REFERENCE_Smooth.SLDPRT reopen=True rebuild=True saved=True errors=0 solids=1
Smooth_adapter.SLDPRT reopen=True rebuild=True saved=True errors=0 solids=1
Smooth_pad_0.SLDPRT reopen=True rebuild=True saved=True errors=0 solids=1
Smooth_pad_1.SLDPRT reopen=True rebuild=True saved=True errors=0 solids=1
Smooth_pad_2.SLDPRT reopen=True rebuild=True saved=True errors=0 solids=1
Smooth_pad_3.SLDPRT reopen=True rebuild=True saved=True errors=0 solids=1
FAIL System.Exception: Cannot reopen C:\Users\sonoi\Luma-Retrofit-CAD\builds\20260913-163314\parts\~$01_Main_shell.SLDPRT error=2
   at Verify.Main(String[] args)

Sketch constraint log

01_Main_shell / Sketch1 before=3 after=3
01_Main_shell / Sketch2 before=3 after=3
02_Service_door_frame / Sketch1 before=3 after=3
03_Upper_front_panel / Sketch1 before=3 after=3
04_Lower_front_panel / Sketch1 before=3 after=3
05_Optics_front_cover / Sketch1 before=3 after=3
06_Input_shutter / Sketch1 before=3 after=3
07_Door_EPDM_gasket / Sketch1 before=3 after=3
08_Universal_mount_plate / Sketch1 before=3 after=3
09_Rear_standoff_L / Sketch1 before=3 after=3
10_Rear_standoff_R / Sketch1 before=3 after=3
11_Dry_electronics_tray / Sketch1 before=3 after=3
11_Dry_electronics_tray / Sketch2 before=3 after=3
12_Dry_electronics_lid / Sketch1 before=3 after=3
13_Controller_UNO_envelope / Sketch1 before=3 after=3
14_Dual_power_fuse_module / Sketch1 before=3 after=3
15_Display_bezel / Sketch1 before=3 after=3
16_Display_protective_window / Sketch1 before=3 after=3
17_QR_label_area / Sketch1 before=3 after=3
18_Status_LED / Sketch1 before=2 after=3
19_Buzzer_envelope / Sketch1 before=2 after=3
20_Sealed_strip_cassette / Sketch1 before=3 after=3
20_Sealed_strip_cassette / Sketch2 before=3 after=3
21_Cassette_sealed_lid / Sketch1 before=3 after=3
22_Optical_chamber / Sketch1 before=3 after=3
22_Optical_chamber / Sketch2 before=3 after=3
23_Optical_removable_lid / Sketch1 before=3 after=3
24_Optical_insert_baffle / Sketch1 before=3 after=3
25_Strip_datum_carrier / Sketch1 before=3 after=3
25_Strip_datum_carrier / Sketch2 before=3 after=3
26_Reagent_strip_envelope / Sketch1 before=2 after=3
27_Scan_rail / Sketch1 before=2 after=3
28_Optical_scan_carriage / Sketch1 before=2 after=3
29_RGB_sensor_envelope / Sketch1 before=2 after=3
30_Left_LED_bracket / Sketch1 before=2 after=3
31_Right_LED_bracket / Sketch1 before=2 after=3
32_Left_LED_envelope / Sketch1 before=2 after=3
33_Right_LED_envelope / Sketch1 before=2 after=3
34_Calibration_tile / Sketch1 before=2 after=3
35_Scan_motor_envelope / Sketch1 before=2 after=3
36_Lead_screw_envelope / Sketch1 before=2 after=3
37_Sample_drawer_module / Sketch1 before=2 after=3
37_Sample_drawer_module / Sketch2 before=2 after=3
38_Wet_dry_barrier / Sketch1 before=2 after=3
39_Drip_tray / Sketch1 before=2 after=3
39_Drip_tray / Sketch2 before=2 after=3
40_Used_strip_waste_cartridge / Sketch1 before=2 after=3
40_Used_strip_waste_cartridge / Sketch2 before=2 after=3
41_Waste_transport_lid / Sketch1 before=2 after=3
42_Waste_closure_slide / Sketch1 before=2 after=3
43_Cleaning_fluid_cartridge / Sketch1 before=2 after=3
43_Cleaning_fluid_cartridge / Sketch2 before=2 after=3
44_Battery_tray / Sketch1 before=2 after=3
44_Battery_tray / Sketch2 before=2 after=3
45_Battery_protected_pack_envelope / Sketch1 before=2 after=3
46_DC_connector_bracket / Sketch1 before=2 after=3
47_DC_connector_envelope / Sketch1 before=2 after=3
48_Cable_gland / Sketch1 before=2 after=3
49_Strain_relief / Sketch1 before=2 after=3
50_Cable_channel / Sketch1 before=2 after=3
51_Door_interlock / Sketch1 before=2 after=3
52_Cartridge_present_switch / Sketch1 before=2 after=3
53_Drip_overflow_sensor / Sketch1 before=2 after=3
54_Strip_jam_home_sensor / Sketch1 before=2 after=3
55_Hinge_lower / Sketch1 before=2 after=3
56_Hinge_upper / Sketch1 before=2 after=3
57_Service_lock / Sketch1 before=2 after=3
58_Tether_eye / Sketch1 before=2 after=3
59_M4_captive_fastener_0 / Sketch1 before=2 after=3
59_M4_captive_fastener_1 / Sketch1 before=2 after=3
59_M4_captive_fastener_2 / Sketch1 before=2 after=3
59_M4_captive_fastener_3 / Sketch1 before=2 after=3
Hook_adapter / Sketch1 before=2 after=3
Hook_front_drop / Sketch1 before=2 after=3
Hook_protective_pad / Sketch1 before=2 after=3
Hook_rear_drop / Sketch1 before=2 after=3
Hook_top_bridge / Sketch1 before=2 after=3
Magnetic_adapter / Sketch1 before=2 after=3
Magnet_pot_0 / Sketch1 before=2 after=3
Magnet_pot_1 / Sketch1 before=2 after=3
Magnet_pot_2 / Sketch1 before=2 after=3
Magnet_pot_3 / Sketch1 before=2 after=3
Partition_adapter / Sketch1 before=2 after=3
Partition_bridge_0 / Sketch1 before=2 after=3
Partition_bridge_1 / Sketch1 before=2 after=3
Partition_fixed_jaw_0 / Sketch1 before=2 after=3
Partition_fixed_jaw_1 / Sketch1 before=2 after=3
Partition_M8_screw_0 / Sketch1 before=2 after=3
Partition_M8_screw_1 / Sketch1 before=2 after=3
Partition_moving_jaw_0 / Sketch1 before=2 after=3
Partition_moving_jaw_1 / Sketch1 before=2 after=3
Partition_pad_front_0 / Sketch1 before=2 after=3
Partition_pad_front_1 / Sketch1 before=2 after=3
Partition_pad_rear_0 / Sketch1 before=2 after=3
Partition_pad_rear_1 / Sketch1 before=2 after=3
Pedestal_adapter / Sketch1 before=2 after=3
Pedestal_ballast_base / Sketch1 before=2 after=3
Pedestal_head / Sketch1 before=2 after=3
Pedestal_tower / Sketch1 before=2 after=3
Rail_adapter / Sketch1 before=2 after=3
Rail_bridge_0 / Sketch1 before=2 after=3
Rail_bridge_1 / Sketch1 before=2 after=3
Rail_front_half_0 / Sketch1 before=2 after=3
Rail_front_half_1 / Sketch1 before=2 after=3
Rail_insert_front_32mm_0 / Sketch1 before=2 after=3
Rail_insert_front_32mm_1 / Sketch1 before=2 after=3
Rail_insert_rear_32mm_0 / Sketch1 before=2 after=3
Rail_insert_rear_32mm_1 / Sketch1 before=2 after=3
Rail_rear_half_0 / Sketch1 before=2 after=3
Rail_rear_half_1 / Sketch1 before=2 after=3
REFERENCE_Partition / Sketch1 before=3 after=3
REFERENCE_Pedestal / Sketch1 before=3 after=3
REFERENCE_Rail / Sketch1 before=3 after=3
REFERENCE_Smooth / Sketch1 before=3 after=3
Smooth_adapter / Sketch1 before=2 after=3
Smooth_pad_0 / Sketch1 before=2 after=3
Smooth_pad_1 / Sketch1 before=2 after=3
Smooth_pad_2 / Sketch1 before=2 after=3
Smooth_pad_3 / Sketch1 before=2 after=3
09_Rear_standoff_L / Fastener_clearance before=3 after=3
10_Rear_standoff_R / Fastener_clearance before=3 after=3
Partition_moving_jaw_0 / Fastener_clearance before=3 after=3
Partition_moving_jaw_1 / Fastener_clearance before=3 after=3
Rail_bridge_0 / Saddle_contact_relief before=3 after=3
Rail_bridge_1 / Saddle_contact_relief before=3 after=3

## Parts and material schedule

Part | Group | Envelope mm | Material / placeholder | Est. kg
01_Main_shell | Core | 230 × 330 × 128 | PC-ABS | 0.740
02_Service_door_frame | Core | 224 × 324 × 5 | PC-ABS | 0.084
03_Upper_front_panel | Core | 194 × 106 × 3 | PC-ABS | 0.059
04_Lower_front_panel | Core | 194 × 67 × 3 | PC-ABS | 0.045
05_Optics_front_cover | Core | 194 × 93 × 3 | PC-ABS | 0.062
06_Input_shutter | Core | 154 × 25 × 3 | PC-ABS | 0.013
07_Door_EPDM_gasket | Core | 224 × 324 × 1 | EPDM | 0.004
08_Universal_mount_plate | Core | 180 × 260 × 4 | 304 stainless steel | 1.495
09_Rear_standoff_L | Core | 12 × 245 × 4 | 304 stainless steel | 0.094
10_Rear_standoff_R | Core | 12 × 245 × 4 | 304 stainless steel | 0.094
11_Dry_electronics_tray | Core | 196 × 96 × 66 | PC-ABS | 0.189
12_Dry_electronics_lid | Core | 190 × 90 × 2 | PC-ABS | 0.039
13_Controller_UNO_envelope | Core | 69 × 54 × 16 | COTS PCB envelope | 0.066
14_Dual_power_fuse_module | Core | 37 × 27 × 16 | COTS electrical envelope | 0.024
15_Display_bezel | Core | 101 × 57 × 1 | PC-ABS | 0.002
16_Display_protective_window | Core | 86 × 42 × 1 | Polycarbonate | 0.004
17_QR_label_area | Core | 27 × 27 × 0.4 | Label | 0.000
18_Status_LED | Core | 5 × 5 × 1 | COTS LED | 0.000
19_Buzzer_envelope | Core | 14 × 14 × 7 | COTS buzzer | 0.002
20_Sealed_strip_cassette | Core | 34 × 130 × 45 | Polypropylene | 0.033
21_Cassette_sealed_lid | Core | 30 × 126 × 2 | Polypropylene | 0.007
22_Optical_chamber | Core | 158 × 59 × 66 | Black PC-ABS | 0.084
23_Optical_removable_lid | Core | 154 × 55 × 2 | Black PC-ABS | 0.019
24_Optical_insert_baffle | Core | 148 × 49 × 7 | Black PC-ABS | 0.009
25_Strip_datum_carrier | Core | 137 × 13 × 8 | Polypropylene | 0.003
26_Reagent_strip_envelope | Core | 125 × 5 × 0.5 | COTS strip envelope | 0.000
27_Scan_rail | Core | 142 × 6 × 6 | 304 stainless steel | 0.041
28_Optical_scan_carriage | Core | 28 × 28 × 3 | Black PC-ABS | 0.002
29_RGB_sensor_envelope | Core | 21 × 21 × 5 | COTS PCB envelope | 0.002
30_Left_LED_bracket | Core | 10 × 16 × 3 | Black PC-ABS | 0.000
31_Right_LED_bracket | Core | 10 × 16 × 3 | Black PC-ABS | 0.000
32_Left_LED_envelope | Core | 6 × 8 × 2 | COTS LED | 0.000
33_Right_LED_envelope | Core | 6 × 8 × 2 | COTS LED | 0.000
34_Calibration_tile | Core | 8 × 8 × 1 | Ceramic reference placeholder | 0.000
35_Scan_motor_envelope | Core | 20 × 20 × 20 | COTS motor | 0.024
36_Lead_screw_envelope | Core | 132 × 3 × 3 | 304 stainless steel | 0.010
37_Sample_drawer_module | Core | 154 × 24 × 51 | Polypropylene | 0.037
38_Wet_dry_barrier | Core | 198 × 3 × 112 | PC-ABS | 0.077
39_Drip_tray | Core | 148 × 12 × 72 | Polypropylene | 0.043
40_Used_strip_waste_cartridge | Core | 142 × 56 × 93 | Polypropylene | 0.078
41_Waste_transport_lid | Core | 138 × 52 × 2 | Polypropylene | 0.004
42_Waste_closure_slide | Core | 125 × 38 × 1 | Polypropylene | 0.004
43_Cleaning_fluid_cartridge | Core | 24 × 60 × 48 | Polypropylene | 0.016
44_Battery_tray | Battery | 81 × 29 × 47 | PC-ABS | 0.027
45_Battery_protected_pack_envelope | Battery | 75 × 23 × 39 | COTS battery envelope | 0.148
46_DC_connector_bracket | DC | 20 × 16 × 3 | PC-ABS | 0.001
47_DC_connector_envelope | DC | 8 × 8 × 13 | COTS connector | 0.001
48_Cable_gland | Core | 12 × 12 × 9 | COTS gland | 0.001
49_Strain_relief | Core | 18 × 12 × 5 | EPDM | 0.001
50_Cable_channel | Core | 8 × 188 × 7 | PC-ABS | 0.006
51_Door_interlock | Core | 10 × 14 × 7 | COTS switch | 0.001
52_Cartridge_present_switch | Core | 8 × 10 × 6 | COTS switch | 0.001
53_Drip_overflow_sensor | Core | 12 × 6 × 2 | COTS PCB envelope | 0.000
54_Strip_jam_home_sensor | Core | 8 × 8 × 5 | COTS sensor | 0.000
55_Hinge_lower | Core | 8 × 8 × 16 | 304 stainless steel | 0.005
56_Hinge_upper | Core | 8 × 8 × 16 | 304 stainless steel | 0.005
57_Service_lock | Core | 12 × 12 × 13 | COTS lock | 0.002
58_Tether_eye | Core | 16 × 16 × 4 | 304 stainless steel | 0.005
59_M4_captive_fastener_0 | Core | 4 × 4 × 7 | 304 stainless steel | 0.001
59_M4_captive_fastener_1 | Core | 4 × 4 × 7 | 304 stainless steel | 0.001
59_M4_captive_fastener_2 | Core | 4 × 4 × 7 | 304 stainless steel | 0.001
59_M4_captive_fastener_3 | Core | 4 × 4 × 7 | 304 stainless steel | 0.001
Partition_adapter | Mount_Partition | 180 × 260 × 4 | 304 stainless steel | 1.495
Rail_adapter | Mount_Rail | 180 × 260 × 4 | 304 stainless steel | 1.495
Hook_adapter | Mount_Hook | 180 × 260 × 4 | 304 stainless steel | 1.495
Pedestal_adapter | Mount_Pedestal | 180 × 260 × 4 | 304 stainless steel | 1.495
Smooth_adapter | Mount_Smooth | 180 × 260 × 4 | 304 stainless steel | 1.495
Magnetic_adapter | Mount_Magnetic | 180 × 260 × 4 | 304 stainless steel | 1.495
Partition_fixed_jaw_0 | Mount_Partition | 40 × 35 × 4 | 304 stainless steel | 0.045
Partition_bridge_0 | Mount_Partition | 4 × 35 × 66 | 304 stainless steel | 0.074
Partition_moving_jaw_0 | Mount_Partition | 40 × 35 × 4 | 304 stainless steel | 0.045
Partition_pad_front_0 | Mount_Partition | 36 × 31 × 2 | EPDM | 0.003
Partition_pad_rear_0 | Mount_Partition | 36 × 31 × 2 | EPDM | 0.003
Partition_M8_screw_0 | Mount_Partition | 8 × 8 × 16 | 304 stainless steel | 0.006
Rail_front_half_0 | Mount_Rail | 54 × 54 × 20 | 304 stainless steel | 0.050
Rail_rear_half_0 | Mount_Rail | 54 × 54 × 20 | 304 stainless steel | 0.050
Rail_insert_front_32mm_0 | Mount_Rail | 46 × 46 × 20 | EPDM | 0.010
Rail_insert_rear_32mm_0 | Mount_Rail | 46 × 46 × 20 | EPDM | 0.010
Rail_bridge_0 | Mount_Rail | 12 × 20 × 5 | 304 stainless steel | 0.010
Partition_fixed_jaw_1 | Mount_Partition | 40 × 35 × 4 | 304 stainless steel | 0.045
Partition_bridge_1 | Mount_Partition | 4 × 35 × 66 | 304 stainless steel | 0.074
Partition_moving_jaw_1 | Mount_Partition | 40 × 35 × 4 | 304 stainless steel | 0.045
Partition_pad_front_1 | Mount_Partition | 36 × 31 × 2 | EPDM | 0.003
Partition_pad_rear_1 | Mount_Partition | 36 × 31 × 2 | EPDM | 0.003
Partition_M8_screw_1 | Mount_Partition | 8 × 8 × 16 | 304 stainless steel | 0.006
Rail_front_half_1 | Mount_Rail | 54 × 54 × 20 | 304 stainless steel | 0.050
Rail_rear_half_1 | Mount_Rail | 54 × 54 × 20 | 304 stainless steel | 0.050
Rail_insert_front_32mm_1 | Mount_Rail | 46 × 46 × 20 | EPDM | 0.010
Rail_insert_rear_32mm_1 | Mount_Rail | 46 × 46 × 20 | EPDM | 0.010
Rail_bridge_1 | Mount_Rail | 12 × 20 × 5 | 304 stainless steel | 0.010
Hook_top_bridge | Mount_Hook | 70 × 4 × 68 | 304 stainless steel | 0.152
Hook_front_drop | Mount_Hook | 70 × 75 × 4 | 304 stainless steel | 0.168
Hook_rear_drop | Mount_Hook | 70 × 60 × 4 | 304 stainless steel | 0.134
Hook_protective_pad | Mount_Hook | 66 × 2 × 53 | EPDM | 0.008
Pedestal_ballast_base | Mount_Pedestal | 500 × 30 × 500 | 304 stainless steel | 60.000
Pedestal_tower | Mount_Pedestal | 60 × 1200 × 6 | 304 stainless steel | 3.456
Pedestal_head | Mount_Pedestal | 100 × 90 × 44 | PC-ABS | 0.455
Smooth_pad_0 | Mount_Smooth | 50 × 55 × 2 | COTS removable pad UNRATED | 0.008
Magnet_pot_0 | Mount_Magnetic | 32 × 32 × 7 | COTS magnet UNRATED | 0.008
Smooth_pad_1 | Mount_Smooth | 50 × 55 × 2 | COTS removable pad UNRATED | 0.008
Magnet_pot_1 | Mount_Magnetic | 32 × 32 × 7 | COTS magnet UNRATED | 0.008
Smooth_pad_2 | Mount_Smooth | 50 × 55 × 2 | COTS removable pad UNRATED | 0.008
Magnet_pot_2 | Mount_Magnetic | 32 × 32 × 7 | COTS magnet UNRATED | 0.008
Smooth_pad_3 | Mount_Smooth | 50 × 55 × 2 | COTS removable pad UNRATED | 0.008
Magnet_pot_3 | Mount_Magnetic | 32 × 32 × 7 | COTS magnet UNRATED | 0.008

## Engineering record

Includes installation compatibility, site survey, assembly/service sequence, parameter register, load calculations, budget allowances and remaining tests.

Read the complete engineering record

# Luma / Rev A engineering prototype

## Design intent and status

Luma is a removable urine-strip reflectance-reader module for existing public toilets. This package is a native SolidWorks engineering layout and reproducible C# generator. It is a prototype starting point, not a clinically validated instrument or fabrication release. Read `checks.txt` and `sketch_checks.txt` in the latest build for actual CAD results. No design certification is implied by the renderings.

The envelope is 230 mm wide × 330 mm high × 134 mm deep, with the rear adapter datum at z = -16 mm, giving a nominal 150 mm projection. Mounts can add rearward depth: 150 mm is the main unit/interface envelope, not a claim that every clamp installation occupies only 150 mm. Coordinates: x left/right, y upward from case bottom, z forward from case rear. Floor stand layouts place the kiosk bottom about 1,000 mm above the base top; final installation height needs a site-specific reach assessment.

Requirements originating in the supplied presentation include the 300–350 × 200–250 × 120–150 mm envelope, TCS34725 sensor, two white LEDs, Arduino Uno, 14-pad strip concept, private results and front servicing. The source presentation's INR 2,667 estimate covers a sensor, Uno, strips, LEDs and jumpers only. It does not establish the cost of an enclosure, mounts, automation, battery, display, or waste system.

## Mechanical architecture

| Zone | Layout / rationale | Open design work |
|---|---|---|
| Dry electronics | Upper tray, sealed lid, full wet/dry shelf below | Select feedthroughs and gasket compression; no leak test performed |
| Unused strips | Separate left cassette with removable lid | Strip supplier and moisture barrier/desiccant system required |
| Optics | Right central chamber, black insert, moving RGB/LED carriage and stationary strip datum | Optical brackets and scan drive require development and calibration |
| Sample input | Front removable tray behind shutter | Manual strip insertion is Rev A; powered transfer to optical datum is not validated |
| Waste | Lower removable tray/cartridge; closure slide for removal | Transfer/ejection chute and self-closing seal require detailed development |
| Cleaning | Independent small fluid-cartridge allowance plus removable wetted inserts | Washing sequence, drain isolation and carryover tests required |
| Power | Battery tray configuration or DC connector configuration | Actual pack, BMS, fuse and rated connector selection required |
| Interface | Display bezel/window, QR area, indicator and lock | Display mount angle, wiring and software are prototype tasks |

The clean cassette is separate from the contaminated measurement path. Baseline operating concept: operator/user inserts an already wetted strip in a keyed disposable carrier; reader checks cover closure and strip presence; optics scan; user receives a private result; used strip goes into a closed waste cartridge. The CAD includes packaging for future feed/eject and cleaning functions. It does not demonstrate a fully automatic urine sampling mechanism. Do not present a clean cassette plus motor envelope as proof of automatic dispensing or fluid handling.

Screen/SMS/payment/clinical algorithms are outside this mechanical CAD implementation. In particular, an offline device cannot verify a new UPI payment or deliver SMS without a suitable connection; local measurement and local display are the offline workflow.

## Configurable dimensions and measured inputs

The generator's `Layout()` lists every part dimension and position in mm. Every extruded feature has a global depth variable. Auto-defined sketch dimensions are linked to individual global variables named `Profile_Sketch_N` or `Back_Sketch_N`. `EnvelopeWidth` and `EnvelopeHeight` are reference metadata, not master assembly controls. To change the whole layout consistently, edit `Layout()` and rebuild into a new timestamped directory. Local edits to one part do not automatically resize adjacent parts.

| Parameter | Prototype value / investigation range | Evidence needed |
|---|---|---|
| Case W/H | 230 / 330 mm | Packaging build and installed clearances |
| Shell / adapter thickness | 3 / 4 mm | Print trials and structural checks; optimise steel mass |
| Strip envelope | 125 × 5 × 0.5 mm | Measure purchased strip, including handle |
| Sensor board envelope | 21 × 21 × 5 mm | Supplier drawing; not all TCS34725 boards match |
| UNO envelope | 69 × 54 × 16 mm | Board plus cable/connector height |
| Sensor-to-pad spacing | Initial envelope around 10–20 mm; explore 5–25 mm on optical jig | Read repeatability, saturation, pad crosstalk |
| LED angle | Explore 30–60° to pad plane | Specular rejection and uniformity tests; brackets presently schematic |
| Pad centres / scan stroke | Supplier-specific; proposed ~100 mm scan range | Actual pad positions and lead-screw travel |
| Pad reaction times | Supplier-defined per pad | Do not use one universal read time |
| Partition thickness | Intended 12–50 mm; represented at 50 mm | Jaw adjustment, screw travel and pad load tests |
| Rail/post diameter | 32 mm insert shown; intended 25/32/38 mm variants | Exact rail geometry, stiffness and permitted load |
| Hook opening | Nominal 55 mm padded gap | Partition top condition, thickness and overhead clearance |
| Battery | 75 × 23 × 39 mm allowance | Energy budget and purchased protected pack |
| Waste capacity | Compute from CAD cavity; do not infer test count from gross volume | Strip stacking, liquid retention and service interval |
| Service space | Reserve 250 mm in front as an initial survey allowance | Full door swing and withdrawal trials |

No assumptions about test-strip chemistry, sensitivity or clinical accuracy are validated here. Fourteen listed analytes do not establish that the selected strip and reader can measure all fourteen reliably.

## Mounting compatibility matrix

All adapters use a common 180 × 260 mm plate with Ø5 mm mounting clearances at x = ±78 mm, y = 49 and 281 mm. Rear stand-offs include Ø4.5 mm screw clearances; the clamp moving jaws include simplified Ø8.1 mm screw passages. Rail bridges have a cylindrical contact relief matching the clamp's 27 mm outside radius. Thread retention, nuts, shoulders, clamp ears and captive-fastener details still require mechanical development before manufacture. Existing infrastructure supplies no new drilled holes.

| Configuration | Suitable site | Exclusions / prerequisites | Reversible installation |
|---|---|---|---|
| Partition | Accessible edge of a structurally suitable 12–50 mm partition | No thin loose sheet, glass edge, fragile finish, moving door or uncertain panel anchorage | Padded opposed jaws and installer-adjusted screws; concept needs load test |
| Rail/post | Approved structural post with unobstructed grip/access zone | Do not load water/flush pipes or impair a required grab rail; obtain asset-owner load information | Split clamp halves, replaceable elastomer inserts and anti-rotation bridge |
| Over-partition hook | Sound exposed partition top | No door closer, door movement or head-clearance conflict; no glass without approved hardware | Padded hook, anti-lift restraint and positive anti-rotation attachment |
| Weighted pedestal | Level floor with enough space and cleaning access | Reject wet slippery/uneven sites unless measured stability and slip resistance pass; no obstructed route | Place and level without anchors; heavy base needs handling provision |
| Smooth surface | Qualified glass/glazed tile with tested mounting product | Reject porous/rough/contaminated surfaces, damaged tile, unknown substrate or no independent tether point | Selected rated removable system; presently not approved for deployment |
| Magnetic | Verified ferromagnetic structural steel | No aluminium, austenitic stainless, thin unsupported sheet, loose coating or no independent tether point | Rated magnetic pots, shear-resisting arrangement and independent tether |

Adhesive and magnetic adapters are reserved configurations, not verified attachment solutions. A safety tether requires an existing suitable independent anchor; if none exists, reject these methods and consider a different mount. No mount is universally compatible. The common enclosure stays consistent while the installer chooses a compatible attachment and checks user clearances.

## Load and stability assumptions

Use the computed component-volume estimate in the generated report as a preliminary dry mass only. Purchased-part densities are placeholders. Add consumables, retained liquid, wiring, all fasteners and manufacturing changes. For initial attachment study use a conservative 10 kg supported device allowance and evaluate 100 N outward and lateral user loads separately. These are chosen design cases, not requirements from a cited standard.

- Gravity for 10 kg: 98.1 N. With 3× static allowance, investigate 294.3 N vertical attachment capacity.
- At a 90 mm centre-of-mass offset, dead-load moment is 8.83 N·m; with that allowance it is 26.5 N·m.
- A 100 N outward load can add a moment depending on its actual application point. Never add moments without checking direction and lever arm.
- Clamp shear estimate: required total normal force N ≥ design shear / measured coefficient of friction. At provisional μ = 0.3 and design shear 294.3 N, N ≥ 981 N across contact faces. Wet friction may be much lower; this is not a clamp rating or tightening-torque prescription.
- The 500 × 500 × 30 mm steel ballast envelope is 60 kg at 8,000 kg/m³. Base-only restoring moment about an edge is approximately 147 N·m when centred. A 100 N horizontal force at 1.30 m gives 130 N·m, margin only 1.13 before sliding or offsets. A 150 N force gives 195 N·m and fails this base-only assessment. Do not call this pedestal vandal-resistant or tip-certified. Its footprint/mass conflict needs site-specific resolution.
- Sliding check uses measured wet-floor friction: R = μ × total weight. Tipping resistance does not establish resistance to sliding.

The CAD density defaults are not engineering material assignments. The generated report estimates mass from explicit geometric volumes and listed densities; SolidWorks mass properties must not be used as certified values until production materials and purchased-component masses are assigned. The final exploded layout is in a separate `Luma_Exploded.SLDASM` document because fixed-component position changes propagated across configurations during testing. `final-interferences.txt` supersedes earlier interference logs after the installed positions are restored.

## Assembly and service sequence

1. Assemble shell, dry compartment, barrier and rear plate. Fit actual seals and perform leak inspection before electronics.
2. Install optical chamber on repeatable datums; install sensor/LED modules and calibration reference. Confirm dark reading with covers closed.
3. Install strip guide, sample carrier and drive hardware. Prove motion and jam recovery without samples before fluid testing.
4. Fit electrical modules, protected battery or DC input, fuse, glands and strain relief. Keep cable routes above liquid retention regions.
5. Fit removable clean cassette, sample drawer, drip tray, cleaning insert and waste cartridge. Verify that each removes from the front without exposure of clean stock.
6. Fit front panels, display window, lock, hinges and interlock. The current CAD uses separate panel bodies; final door fasteners and full hinge swing require detailing.
7. Choose a compatible mount using the survey below. Perform an instrumented proof test off-site before public deployment.
8. Maintenance: disable motion; close waste cartridge slide; withdraw and replace waste cartridge; remove/wash or replace wetted insert; inspect seals; refill clean stock through the clean access path; replace protected battery if used; close and lock covers; run reference and sensor checks.

The used-strip cartridge must not be emptied through the clean compartment. The cartridge slide must close before removal. Opening the service door disables motion; a missing/full cartridge inhibits testing; jam/overflow states stop further sample intake. Sensor boxes in the model reserve these functions but do not implement electrical interlocks.

## Site survey / installer record

- Record fixture type, photographs, mounting surface dimensions, owner approval, material and structural condition.
- Measure free width/depth, opening doors, cleaner access and remaining circulation space.
- Identify accessible partition edge or qualified support, exact thickness/diameter and a compatible mount.
- Determine permitted surface pressure, clamp load and removable-product compatibility with the finish.
- Check display/sample reach with intended users; inspect for privacy conflicts and sharp/pinch points.
- Verify clear access to flush controls, grab rails, toilet/urinal, door latches and emergency routes.
- Identify existing safe power source or use a removable battery. No new building wiring or plumbing.
- Check the actual installed projection including mount hardware and cable bend radius.
- Confirm front service space and a hygienic route for replacement cartridges.
- For optional mounts, record tether anchor, substrate verification and applicable supplier rating.
- For pedestal, measure levelness and wet friction; prove stability at actual mass, height and applied loads.
- Reject the site if none of the reversible options passes these checks.

## Verification and remaining development

| Item | Current evidence | Required before fabrication/deployment |
|---|---|---|
| Native geometry / rebuild | CAD generator checks extrusions and saves; inspect generated logs | Reopen all final references and resolve rebuild errors |
| Sketch constraint state | 125 inspected sketches fully constrained after final detailing; state 3 | Recheck after dimensional or mechanism changes |
| Interference | SolidWorks static interference log for default configuration | Classify intentional contact, resolve unintended overlap; inspect all moving states |
| Envelope | Part and assembly bounding checks in report | Actual mount and site envelope verification |
| Optical geometry | Layout only | Bench study, repeatable datums, black finish, pad-specific calibration |
| Feed/eject | Packaging allowance | Detailed kinematics and physical strip-jam/carryover tests |
| Hygiene | Separated compartments and removable trays | Leak, cleaning efficacy, liquid carryover, disinfectant compatibility |
| IP54/IP55 | Design target only | Selected seals, drainage/vents and tested complete enclosure |
| User/service clearance | Concept envelope only | Door sweep, reach, pinch-point and maintenance demonstration |
| Reversible mounts | CAD concepts | Load paths, clamp hardware, surface damage and creep/pull tests |
| Manufacturing | Printed prototype and steel bracket concepts | Fillets, draft, rib/boss design, bend radii, tolerances, threaded inserts |
| CAD assembly mechanism | Fixed components for packaging | Mates, bearings, linkages, travel stops and motion study |
| Clinical performance | None | Appropriate analytical/clinical validation for chosen consumables |

Optional external auto-flush actuator is deliberately not installed in this baseline: no specific existing flush-button or lever geometry was supplied, and core measurement is independent of plumbing. A future removable actuator must preserve manual operation and spring-return safely on power loss.

## Prototype cost allowances (INR, not supplier quotes)

| Category | Planning allowance |
|---|---:|
| Sensor, Uno, LEDs and wiring | 1,167 from presentation, excludes its strip pack |
| 100-strip pack | 1,500 from presentation; confirm supplier and compatibility |
| Printed enclosure / removable trays | 2,000–4,500 |
| One mechanical mount / locks / seals / fasteners | 1,500–3,500 |
| Display / interface | 500–1,500 |
| Motion / bearings / driver / interlocks | 1,000–3,000 |
| Power / protection | 700–2,000 |
| Optical finish / calibration / cleaning provisions | 500–1,500 |
| Total, before stand / connectivity / labour / validation | 8,867–18,667 |

Do not claim the complete kiosk meets an INR 3,000 target. The heavy pedestal, tooling and clinical validation are separate costs. Use these allowances to decide what to prototype first, then replace them with dated supplier quotes.

## Source and reproducibility

Source idea: `Smart-Health-Kiosks-Democratizing-Diagnostics-via-Public-Infrastructure.pdf.pdf`, supplied by the user, especially pages 4–7, 10–11. User's pasted request controls scope; the PDF is supporting reference material. Geometric/API implementation follows local SOLIDWORKS 2026 interop signatures and official documentation:

- https://help.solidworks.com/2023/English/api/sldworksapi/SOLIDWORKS.Interop.sldworks~SOLIDWORKS.Interop.sldworks.ISketchManager~CreateCornerRectangle.html
- https://help.solidworks.com/2020/English/api/sldworksapi/Insert_Feature_Extrusion_Example_VB.htm

Run `src/Build.ps1` from Windows PowerShell on the same Windows installation with a licensed, available SolidWorks 2026. The script compiles a 64-bit .NET Framework C# executable against installed interop libraries. No API key or cloud CAD service is needed. It creates a new timestamped build and never overwrites prior builds or user CAD models. The SolidWorks install folder is read from the registry (override with the `SOLIDWORKS_DIR` environment variable) and new documents use the default templates set in SolidWorks under Tools > Options > Default Templates, so no paths need editing on another PC.

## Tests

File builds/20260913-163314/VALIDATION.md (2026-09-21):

# Validation record

- 105 model components and 4 host-reference parts measured.
- 109 parts rebuilt with one solid body each.
- 125 sketches inspected; 0 not fully constrained after anchoring.
- 0 nominal-envelope/body-count discrepancies at 0.15 mm tolerance.

The raw verifier log ends with an attempted read of a transient SolidWorks '~$' lock file. This is not a CAD part. All 109 real part files had already completed reopening, rebuilding, saving and measurement. The generator's file filter now excludes lock files; no real part was skipped.

Final assembly placement and collision results are in final-interferences.txt. The independent exploded assembly prevents its component offsets from propagating to installed configurations. Static model checks do not establish working strip transport, structural capacity, hygiene performance or clinical accuracy.

## Final static assembly check

- Partition_DC INTERFERENCE_COUNT=0
- Partition_Battery INTERFERENCE_COUNT=0
- Rail_DC INTERFERENCE_COUNT=0
- Rail_Battery INTERFERENCE_COUNT=0
- Hook_DC INTERFERENCE_COUNT=0
- Hook_Battery INTERFERENCE_COUNT=0
- Pedestal_DC INTERFERENCE_COUNT=0
- Pedestal_Battery INTERFERENCE_COUNT=0
- Smooth_DC INTERFERENCE_COUNT=0
- Smooth_Battery INTERFERENCE_COUNT=0
- Magnetic_DC INTERFERENCE_COUNT=0
- Magnetic_Battery INTERFERENCE_COUNT=0

Only static solid interference is assessed. This does not prove clearance throughout motion, mount load capacity or a functioning feed/eject mechanism.

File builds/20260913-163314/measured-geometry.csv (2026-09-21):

Part | Width_mm | Height_mm | Depth_mm | Volume_mm3 | Solids | RebuildOK
01_Main_shell | 230 | 330 | 128 | 643200 | 1 | True
02_Service_door_frame | 224 | 324 | 5 | 72800 | 1 | True
03_Upper_front_panel | 194 | 106 | 3 | 51612 | 1 | True
04_Lower_front_panel | 194 | 67 | 3 | 38994 | 1 | True
05_Optics_front_cover | 194 | 93 | 3 | 54126 | 1 | True
06_Input_shutter | 154 | 25 | 3 | 11550 | 1 | True
07_Door_EPDM_gasket | 224 | 324 | 1 | 3252 | 1 | True
08_Universal_mount_plate | 180 | 260 | 4 | 186885.84073464 | 1 | True
09_Rear_standoff_L | 12 | 245 | 4.09324511909274 | 11632.77219198 | 1 | True
10_Rear_standoff_R | 12 | 245 | 4.09324511909274 | 11632.77219198 | 1 | True
11_Dry_electronics_tray | 196 | 96 | 66 | 164556 | 1 | True
12_Dry_electronics_lid | 190 | 90 | 2 | 34200 | 1 | True
13_Controller_UNO_envelope | 69 | 54 | 16 | 59616 | 1 | True
14_Dual_power_fuse_module | 37 | 27 | 16 | 15984 | 1 | True
15_Display_bezel | 101 | 57 | 1 | 2016 | 1 | True
16_Display_protective_window | 86 | 42 | 1 | 3612 | 1 | True
17_QR_label_area | 27 | 27 | 0.4 | 291.6 | 1 | True
18_Status_LED | 5 | 5 | 1 | 19.63495408 | 1 | True
19_Buzzer_envelope | 14 | 14 | 7 | 1077.56628018 | 1 | True
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

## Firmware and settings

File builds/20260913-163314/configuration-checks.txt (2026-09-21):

Partition_DC active=73
Partition_Battery active=73
Rail_DC active=71
Rail_Battery active=71
Hook_DC active=65
Hook_Battery active=65
Pedestal_DC active=64
Pedestal_Battery active=64
Smooth_DC active=65
Smooth_Battery active=65
Magnetic_DC active=65
Magnetic_Battery active=65

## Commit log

2026-09-21 Make the model openable without SolidWorks 2026
    - Add an offline browser 3D viewer (START.html) with all 18 configurations,
    part info from the BOM, X-ray, isolate/hide and screenshots
    - Export STEP AP214 per configuration and STL per part (src/Export.cs);
    viewer placements are checked against SolidWorks component boxes
    - Add Build.ps1 -ExportOnly to refresh exports after editing the model
    - Find SolidWorks, its default templates and Node.js automatically;
    resolve LATEST.txt relative to the checkout
    - Remove failed builds, the stale deliverables copy, compiled binaries,
    SolidWorks interop DLLs and BMP duplicates; add .gitignore/.gitattributes
    - Rewrite README around how to open the mo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
    [01_Main_shell.SLDPRT, 01_Main_shell.stl, 02_Service_door_frame.SLDPRT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]
2026-09-21 Add website build guide with parts list, layout and assembly steps
    - build-guide.html (generated by src/Guide.js from BOM.csv): purchased
    components with specifications fitted to the CAD envelopes, printed,
    steel and EPDM part tables, mount kits, labelled layout diagrams,
    eight illustrated assembly steps, suggested Arduino wiring, testing,
    servicing and budget
    - 3D viewer: links like Viewer.html#Config/part,part highlight parts and
    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
